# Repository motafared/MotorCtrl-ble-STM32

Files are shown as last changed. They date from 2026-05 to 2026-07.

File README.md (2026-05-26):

# MotorCtrl BLE — STM32WB55 Dual BLDC Motor Controller (Phase 2)

Wireless control and live telemetry for a **dual 12 V BLDC motor controller**, built on the
**WeAct STM32WB55** (Cortex-M4 + Bluetooth LE 5.0). Phase 2 adds BLE control plus a
**Web Bluetooth dashboard** — drive the motors and watch live data from a phone or laptop, with
no app install. The original push-button control still works in parallel.

> 🌐 **Live dashboard:** **https://motafared.github.io/MotorCtrl-ble-STM32/** — open in
> Chrome / Edge on desktop or Android (no install). Needs Bluetooth on; Android also needs
> Location enabled for BLE scanning.
>
> 📄 **Full delivery document:** [`docs/phase2_delivery.md`](docs/phase2_delivery.md)
> ([styled HTML](docs/phase2_delivery.html)) — scope, BOM, wiring, flashing, GATT reference,
> dashboard usage, troubleshooting.

## Repository layout (monorepo)

```
Phase2-Project/
├── firmware/   STM32WB55 application (STM32CubeIDE) + BLE GATT services
├── WebApp/     Web Bluetooth dashboard (single-page, no install)
├── kicad/      Hardware design (KiCad, generated from SKiDL)
└── docs/       Delivery doc + connection diagrams
```

## At a glance

- **Two BLDC motors**, closed-loop PID speed control (100 ms tick), tachometer feedback.
- **Three run modes:** Timed run (default 35 s) · Continuous (CONTINUE button: run while held; app command: latched until Stop) · Stopped.
- **Live telemetry:** actual speed, cumulative rotations, elapsed time, and run state.
- **Buttons + BLE in parallel** — the dashboard tracks physical button presses live.

## Hardware

| Item | Detail |
|---|---|
| MCU | WeAct STM32WB55 Core Board (STM32WB55CGU6, 64 MHz, BLE 5.0) |
| Motors | 2× BLDC 12 V 4-wire |
| PWM | PA0 (M1) / PA1 (M2) — TIM2, 20 kHz |
| Tachometer | PA8 (M1) / PA9 (M2) — TIM1 input capture |
| PID tick | TIM16 — 100 ms |
| Buttons | PA2 STOP, PA3 START, PA4 CONTINUE — EXTI, **active-HIGH, internal pull-down** |
| Status LED | PE4 (blue) — ON running, 5 Hz heartbeat |

## BLE GATT

Advertised name **`MotorCtrl`**. All multi-byte values little-endian.

**Control service `0x0001`**

| Char | UUID | Type | Access | Meaning |
|---|---|---|---|---|
| TSM1 | 0x0002 | u16 | R/W | Target speed M1 (RPM) |
| TSM2 | 0x0003 | u16 | R/W | Target speed M2 (RPM) |
| CT | 0x0004 | u16 | R/W | Cycle time (s) |
| CMD | 0x0005 | u8 | W | `0x01` start timed · `0x02` stop · `0x03` start continuous |

**Telemetry service `0x0010`** (Read / Notify)

| Char | UUID | Type | Meaning |
|---|---|---|---|
| ASM1 / ASM2 | 0x0011 / 0x0012 | u16 | Actual speed M1 / M2 (RPM) |
| RM1 / RM2 | 0x0013 / 0x0014 | u32 | Cumulative rotations M1 / M2 |
| ET | 0x0015 | u16 | Elapsed time (s) |
| STATUS | 0x0016 | u8 | Run state: `0` idle · `1` timed · `2` continuous |

Reads return live values (refreshed from firmware state on each read). STATUS is notified on
every transition — BLE command, timed auto-stop, **and** physical button presses.

## Build & flash (firmware)

This project is **STM32CubeIDE only**.

1. **One-time:** flash the CPU2 BLE stack with STM32CubeProgrammer — `stm32wb5x_FUS_fw.bin` at
   `0x080EC000` (skip if FUS ≥ 1.2.0), then `stm32wb5x_BLE_Stack_full_fw.bin` at `0x080C0000`.
2. Open `firmware/` in STM32CubeIDE → **Build All** → **Run** to flash the application.

**Build modes** — one switch in `firmware/Core/Inc/main.h`:

| `MOTOR_MODE` | Tacho PPR | PWM polarity | Use |
|---|---|---|---|
| `MODE_KHALED` | 2 | non-inverted | bench testing |
| `MODE_TOON` | 6 | inverted | client hardware |

Defaults: target 1200 RPM/motor, 35 s cycle, PID `Kp = 0.012`.

## Run the dashboard

**Hosted (no install):** open **https://motafared.github.io/MotorCtrl-ble-STM32/** in Chrome / Edge.

Or serve it locally:

```bash
cd WebApp
python -m http.server 8000      # then open http://localhost:8000 in Chrome
```

- **Browsers:** Chrome / Edge / Brave (desktop, Android); **Bluefy** on iOS.
- Web Bluetooth needs a secure context (`https://` or `http://localhost`); `file://` won't work.
- After flashing new firmware, **hard-reload** the page (Ctrl+Shift+R) to avoid a cached script.

## License

Proprietary — all rights reserved. Client project for Toon.

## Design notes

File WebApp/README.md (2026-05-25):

# MotorCtrl WebApp

Web Bluetooth dashboard for the **MotorCtrl** STM32WB55 BLDC controller (Phase 2 firmware).

- Connect to the board over BLE 5 directly from the browser — no install.
- Live actual / target RPM for both motors, rotation counts, elapsed time.
- Start (timed), Stop, Start (continuous) commands.
- Live speed chart (60-second rolling window).
- Settings are locked while the motors are running (stop first to change).

## Browser support

- **Desktop / Android:** Google Chrome, Edge, Brave (any Chromium with Web Bluetooth).
- **iOS / iPadOS:** [Bluefy](https://apps.apple.com/app/bluefy-web-ble-browser/id1492822055) (free, App Store).

Web Bluetooth requires a secure context. Use `https://` (e.g. GitHub Pages) or `http://localhost` for development. `file://` is **not** supported.

## Run locally

```bash
python -m http.server 8000
# then open http://localhost:8000
```

## Firmware

See the firmware repo: [MotorCtrl-ble-STM32](https://github.com/motafared/MotorCtrl-ble-STM32).

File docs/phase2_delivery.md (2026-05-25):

# MotorCtrl — Phase 2 Delivery (BLE Wireless Control)

**Client:** Toon
**Scope:** STM32 firmware + Web Bluetooth dashboard that add wireless control and
live telemetry to the Phase 1 dual-BLDC motor controller.
**Hardware:** WeAct STM32WB55 Core Board (STM32WB55CGU6), two 12 V 4-wire BLDC
motors with 1-pulse-per-revolution tachometers, three push-buttons, status LED.

---

## 1. What this is

Phase 1 was a dual-BLDC speed controller on an STM32F103: two motors, PID speed
control, three run modes (timed / continuous / stopped), driven by on-board
buttons. **Phase 2 moves it to the STM32WB55** (same STM32 ecosystem, plus
built-in Bluetooth LE 5.0) and adds:

- **BLE control** — set target speeds and cycle time, and start/stop the motors,
  from a phone or laptop with no app install (a web page over Web Bluetooth).
- **BLE telemetry** — live actual speed, rotation counts, elapsed time, and run
  state pushed to the dashboard as they change.
- The original **push-button control still works** in parallel with BLE, and the
  dashboard tracks button presses live.

**In scope for Phase 2:**
- STM32WB55 firmware: motor PID port, BLE GATT services (control + telemetry),
  button + timed-cycle logic, status LED.
- Web Bluetooth dashboard (single-page, no install).
- This documentation.

**Out of scope / deferred (see §10):**
- Custom PCB build (a KiCad design exists under `kicad/`, not yet fabricated).
- Multi-board control (up to 4 boards in one browser tab) — architecture is
  ready, UI is single-board.
- Persisting settings across power cycles (flash storage).

---

## 2. Hardware bill of materials

| Item | Notes |
|---|---|
| WeAct STM32WB55 Core Board | STM32WB55CGU6, 64 MHz, BLE 5.0, supplied by client |
| 2× 12 V 4-wire BLDC motors | PWM + tachometer (1 pulse/rev sensed; see §4 for PPR) |
| 12 V DC supply | Motor rail; logic is 3.3 V from the board regulator |
| 3× momentary push-buttons | START / STOP / CONTINUE — see §3.2 wiring (active-HIGH) |
| 1× LED + ~1 kΩ resistor | Status indicator on PE4 |
| ST-LINK (or on-board) | Flashing / debug over SWD |
| Phone or PC with Chrome/Edge | To run the Web Bluetooth dashboard (§7) |

A detailed pin-by-pin wiring sheet and a styled connection diagram live in
`kicad/MotorCtrl/WIRING.md` and `kicad/MotorCtrl/connections.html`.

---

## 3. Hardware connections

All control logic is 3.3 V. The motors run on +12 V; share a common ground
between the 12 V supply and the board.

### 3.1 Pin map (STM32WB55, 64 MHz)

| Signal | STM32 Pin | Peripheral | Notes |
|---|---|---|---|
| Motor 1 PWM | PA0 | TIM2_CH1 | 20 kHz PWM |
| Motor 2 PWM | PA1 | TIM2_CH2 | 20 kHz PWM |
| Motor 1 tacho | PA8 | TIM1_CH1 | input capture |
| Motor 2 tacho | PA9 | TIM1_CH2 | input capture |
| Button STOP | PA2 | EXTI2 | active-HIGH, internal pull-down |
| Button START | PA3 | EXTI3 | active-HIGH, internal pull-down |
| Button CONTINUE | PA4 | EXTI4 | active-HIGH, internal pull-down |
| Status LED (blue) | PE4 | GPIO out | ON running, 5 Hz heartbeat |
| SWD debug | PA13 / PA14 | SWDIO / SWCLK | flashing |

Timer setup: TIM2 prescaler 0 / period 3199 → 20 kHz PWM at 64 MHz · TIM1
prescaler 999 → tacho input capture · TIM16 prescaler 6399 / period 999 →
100 ms PID + telemetry tick.

### 3.2 Push-buttons (active-HIGH, internal pull-down)

The buttons are wired **active-HIGH**: pressing a button connects the MCU pin to
**+3V3**. The MCU's **internal pull-down** holds the pin LOW when released, so
**no external pull resistor is required**.

```
   Push-buttons                      STM32WB55 board
   ┌─────────────────────┐          ┌──────────────────────────┐
   │ START   SW1 ────────├─────────►┤ PA3   BTN_START          │ EXTI3  rising (press)
   │ STOP    SW2 ────────├─────────►┤ PA2   BTN_STOP           │ EXTI2  rising (press)
   │ CONT    SW3 ────────├─────────►┤ PA4   BTN_CONTINUE       │ EXTI4  both edges
   │ (common → +3V3)     │          │   (internal pull-down ON) │
   └─────────────────────┘          └──────────────────────────┘
```

- **Idle = LOW**, **pressed = HIGH**.
- START / STOP act on the **rising edge** (the press).
- CONTINUE uses **both edges**: rising = start (runs while held), falling =
  release = stop.
- Firmware debounces 50 ms in software; an optional series resistor + small cap
  to GND is fine for ESD but not electrically required.

> ⚠ This differs from the older active-low note in some early hardware drafts.
> The firmware is the source of truth (`Core/Src/main.c` → `MX_GPIO_Init`,
> `GPIO_PULLDOWN`). The KiCad/SKiDL source (`kicad/MotorCtrl/motorctrl.py`) must
> match: button common to **+3V3**, external pull-ups removed.

### 3.3 Motors

```
   Motor M1 (4-wire)                 STM32WB55 board
   +12V ───────────── +12 V rail
   GND  ───────────── GND (common with board GND)
   PWM  ◄──────────── PA0  (TIM2_CH1)
   Tacho ──────────►  PA8  (TIM1_CH1)

   Motor M2 (4-wire)
   PWM  ◄──────────── PA1  (TIM2_CH2)
   Tacho ──────────►  PA9  (TIM1_CH2)
```

Each tacho line typically needs a pull-up to +3V3. The PWM output idles at the
inactive level until a motor is started (see §9 troubleshooting on bench
behaviour with no motor connected).

---

## 4. Build modes (Khaled vs Toon)

A single switch in `Core/Inc/main.h` selects between the bench-test setup and the
client hardware, because they differ in tachometer pulses-per-revolution and PWM
polarity:

```c
#define MOTOR_MODE   MODE_KHALED   /* <<< switch here: MODE_KHALED or MODE_TOON */
```

| Mode | `MOTOR_PPR` | PWM polarity | Use |
|---|---|---|---|
| `MODE_KHALED` | 2 | `TIM_OCPOLARITY_HIGH` (not inverted) | bench testing |
| `MODE_TOON` | 6 | `TIM_OCPOLARITY_LOW` (inverted) | client hardware |

`M1_PPR` / `M2_PPR` follow `MOTOR_PPR`. PWM polarity is re-applied in the
`USER CODE BEGIN TIM2_Init 2` block of `Core/Src/main.c` so it survives CubeMX
regeneration. **Flip the one `MOTOR_MODE` line and rebuild** to switch targets —
nothing else changes. Default ships as `MODE_KHALED`.

Other defaults (`main.h`): target speed 1200 RPM per motor, cycle time 35 s
(timed mode), PID `Kp = 0.012`, `Ki = 0`, `Kd = 0`, 100 ms control tick.

---

## 5. Firmware install

The STM32WB55 has **two cores**: the application runs on the CM4; the BLE stack
runs on a CM0+ co-processor and is flashed **separately**. You must have the BLE
stack in place once before the application's Bluetooth will work.

### 5.1 Flash the BLE co-processor stack (one-time, STM32CubeProgrammer)

Binaries come from the **STM32CubeWB** package:
`STM32Cube_FW_WB_Vx.x.x\Projects\STM32WB_Copro_Wireless_Binaries\STM32WB5x\`.

1. Connect via ST-LINK; open **STM32CubeProgrammer**.
2. Flash **FUS** `stm32wb5x_FUS_fw.bin` at **`0x080EC000`** — skip if a recent
   FUS (≥ 1.2.0) is already present.
3. Flash the **BLE Full stack** `stm32wb5x_BLE_Stack_full_fw.bin` at
   **`0x080C0000`** (this project uses `BLE_STACK=FULL`).
4. Verify in the **Wireless** tab — it shows the installed FUS and BLE versions.

(If the stack is already installed and verified, skip to 5.2.)

### 5.2 Build and flash the application (STM32CubeIDE)

This project is **STM32CubeIDE only** (ignore the `EWARM/` folder).

1. Open **STM32CubeIDE** → **File → Open Projects from File System** → select the
   `Phase2/` project folder.
2. Confirm `MOTOR_MODE` in `main.h` (§4) is set for the board you're flashing.
3. **Project → Build All** — should complete with **0 errors**.
4. **Run → Run As → STM32 C/C++ Application** to flash the CM4 application at
   `0x08000000` and start it.

### 5.3 Verify it's alive

- The **blue LED (PE4)** is OFF when stopped. Press **START** → motors run and the
  LED blinks ~5 Hz (the PID-tick heartbeat). Press **STOP** → LED off.
- From a phone/PC, the board advertises as **`MotorCtrl`** and is visible to a BLE
  scanner (nRF Connect) or the dashboard (§7).

---

## 6. BLE GATT reference

- **Advertised name:** `MotorCtrl`
- **All multi-byte values are little-endian.**
- Two services: **Control** (write settings + commands) and **Telemetry**
  (read + notify live values).

### 6.1 Control service — UUID `0x0001`

| Characteristic | UUID | Type | Properties | Meaning |
|---|---|---|---|---|
| TSM1 | `0x0002` | uint16 | Read / Write | Target speed motor 1 (RPM) |
| TSM2 | `0x0003` | uint16 | Read / Write | Target speed motor 2 (RPM) |
| CT | `0x0004` | uint16 | Read / Write | Cycle time (seconds, timed mode) |
| CMD  | `0x0005` | uint8  | Write | Command: `0x01` start timed · `0x02` stop · `0x03` start continuous |

### 6.2 Telemetry service — UUID `0x0010`

| Characteristic | UUID | Type | Properties | Meaning |
|---|---|---|---|---|
| ASM1 | `0x0011` | uint16 | Read / Notify | Actual speed motor 1 (RPM) |
| ASM2 | `0x0012` | uint16 | Read / Notify | Actual speed motor 2 (RPM) |
| RM1  | `0x0013` | uint32 | Read / Notify | Cumulative rotations motor 1 |
| RM2  | `0x0014` | uint32 | Read / Notify | Cumulative rotations motor 2 |
| ET | `0x0015` | uint16 | Read / Notify | Elapsed time (seconds) |
| STATUS | `0x0016` | uint8 | Read / Notify | Run state: `0` idle · `1` timed · `2` continuous |

### 6.3 Behaviour notes

- **Reads return live values.** A read of any characteristic refreshes it from the
  firmware's current state before answering (not a stale cache), so a client that
  connects mid-run sees the true values immediately.
- **STATUS is the source of truth for run state.** The firmware notifies STATUS on
  **every** transition — BLE command, timed auto-stop, *and* physical button
  presses — so a dashboard always reflects what the board is actually doing.
- Telemetry notifications are emitted every 100 ms while running, from a safe BLE
  task context (not from an interrupt).

---

## 7. Web Bluetooth dashboard

A single-page dashboard (in the `WebApp/` folder) that connects to the board over
BLE — **no install**.

### 7.1 Browser support

- **Desktop / Android:** Google Chrome, Edge, or Brave (any Chromium with Web
  Bluetooth).
- **iPhone / iPad:** the **Bluefy** browser (free, App Store) — Safari does not
  support Web Bluetooth.
- Web Bluetooth requires a **secure context**: serve over `https://` (e.g. GitHub
  Pages) or `http://localhost`. Opening the file directly (`file://`) will not
  work.

### 7.2 Run it locally

```bash
cd WebApp
python -m http.server 8000
# open http://localhost:8000 in Chrome
```

### 7.3 Using it

1. Click **Connect** and pick **MotorCtrl** from the chooser.
2. The dashboard hydrates from the board: target speeds, cycle time, live RPM,
   rotation counts, elapsed time, and run state.
3. Set **Target** speed per motor and the **Cycle** time, then **Start Timed**,
   **Start Continuous**, or **Stop**.
4. The **Live Speed** chart shows actual vs target RPM over a 60 s rolling window.
5. Settings are **locked while running** — stop first to change them.
6. The state chip and lock track the board live, including physical-button
   presses and the automatic stop at the end of a timed run.

> **After flashing new firmware, hard-reload the page** (Ctrl+Shift+R). Browsers
> cache the dashboard's scripts; a stale cache can keep telemetry working while
> new features silently don't.

---

## 8. Operation summary

| Action | Button | BLE command | Result |
|---|---|---|---|
| Start timed run | START (PA3) | CMD `0x01` | Both motors run to target speed; auto-stop after the cycle time (default 35 s). |
| Stop | STOP (PA2) | CMD `0x02` | Motors stop immediately, any mode. |
| Start continuous | CONTINUE (PA4), held | CMD `0x03` | Motors run; **button mode stops on release**. |

- **Speed control** is closed-loop PID using the tachometer; target defaults to
  1200 RPM and is adjustable live over BLE.
- **Rotations** accumulate while running and are reported live and at cycle end.
- The **blue LED** is ON (blinking 5 Hz) while running, OFF when stopped.

---

## 9. Troubleshooting

| Symptom | Likely cause | Fix |
|---|---|---|
| Dashboard can't find the board | BLE stack not flashed, or board not advertising | Verify CPU2 stack in CubeProgrammer **Wireless** tab (§5.1); confirm `MotorCtrl` shows in a BLE scanner |
| "GATT Server is disconnected. Cannot retrieve services" (intermittent) | Web Bluetooth + WB connection race | The dashboard retries automatically; if persistent, forget the device in OS Bluetooth and reconnect |
| Connected, telemetry works, but run-state/buttons don't update the UI | Browser serving a cached old dashboard | **Hard-reload** the page (Ctrl+Shift+R), or DevTools → Network → "Disable cache" |
| No PWM on the analyser with no motor connected | Open-loop PID winds duty to 100% (no feedback) → pin sits constant HIGH | Expected on the bench; connect a motor for closed-loop, or temporarily zero the PID gains / force a fixed duty |
| Motor doesn't reach/track speed | Wrong `MOTOR_MODE` PPR, or tacho not wired | Confirm `MODE_KHALED` (PPR 2) vs `MODE_TOON` (PPR 6) matches the motor; check tacho pull-up and wiring |
| Button does nothing / triggers inverted | Button wired active-low instead of active-HIGH | Wire button common to **+3V3** (§3.2); firmware uses internal pull-down |
| Settings won't change in the dashboard | Motors are running (settings locked) | Press **Stop** first, then edit |
| Build fails after editing BLE chars in CubeMX | CubeMX caps STM32WB services at 5 characteristics | The 6th char (STATUS) is added in code, not the `.ioc`; see §10 |

---

## 10. Production notes & deferred items

- **STM32WB CubeMX 5-characteristic limit.** The CubeMX GATT designer caps each
  STM32WB service at 5 characteristics. The 6th telemetry characteristic
  (**STATUS**) is therefore added **manually in code** (ST's recommended
  workaround: `aci_gatt_add_char()` + increased `max_attr_record`). Because it
  lives partly outside CubeMX user-code regions, **re-running CubeMX "Generate
  Code" will wipe parts of it** — re-apply from the firmware history if you
  regenerate, or freeze the `.ioc`.
- **Multi-board dashboard.** The web app's BLE layer is one-instance-per-device
  and event-driven, ready for the "up to 4 boards in one tab" requirement; only
  the UI is currently single-board.
- **Persistent settings.** Target speeds / cycle time reset to defaults on power
  cycle. A future revision could store them in flash.
- **Custom PCB.** A KiCad design exists under `kicad/MotorCtrl/` (SKiDL source
  `motorctrl.py`). It must be brought in line with the firmware before
  fabrication — notably the **active-HIGH button wiring** (§3.2).
- **Watchdog / fault handling.** No IWDG is enabled; consider one for unattended
  operation.

---

*Document version: Phase 2 — 2026-05-25*

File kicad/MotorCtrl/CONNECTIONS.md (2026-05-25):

# MotorCtrl — Connections to the STM32 Board

Wiring of the **STM32WB55** carrier board (Phase 2), one connection group per
diagram. Pins mirror the firmware map in `Core/Inc/main.h`; source of truth is
the SKiDL design [motorctrl.py](motorctrl.py).

Board MCU module: **WeAct STM32WB55CGU6** (`U2`). All `3V3` logic; motors run on
the `+12V` rail.

---

## 1. STM32 ↔ Motors

Two 4-wire BLDC motors on connectors `J3` (M1) and `J4` (M2). PWM drives the
motor; the tacho returns one pulse train per revolution.

```
   Motor M1  (J3, 4-wire)            STM32WB55 board (U2)
   ┌─────────────────────┐          ┌──────────────────────────┐
   │ +12V   (J3.2)       ├── +12V ───┤ +12V rail                │
   │ GND    (J3.1)       ├── GND  ───┤ GND                      │
   │ PWM    (J3.3)       ├◄──────────┤ PA0   M1_PWM             │ TIM2_CH1
   │ Tacho  (J3.4)       ├──────────►┤ PA8   M1_TACH            │ TIM1_CH1
   └─────────────────────┘          └──────────────────────────┘

   Motor M2  (J4, 4-wire)            STM32WB55 board (U2)
   ┌─────────────────────┐          ┌──────────────────────────┐
   │ +12V   (J4.2)       ├── +12V ───┤ +12V rail                │
   │ GND    (J4.1)       ├── GND  ───┤ GND                      │
   │ PWM    (J4.3)       ├◄──────────┤ PA1   M2_PWM             │ TIM2_CH2
   │ Tacho  (J4.4)       ├──────────►┤ PA9   M2_TACH            │ TIM1_CH2
   └─────────────────────┘          └──────────────────────────┘
```

- Each tacho line has a pull-up to `+3V3` on the board: `R1` (M1), `R2` (M2).
- PWM is 20 kHz (TIM2); tacho is timer input-capture (TIM1).

---

## 2. STM32 ↔ Buttons

Three momentary push-buttons. Each is debounced on the board: pull-up to `+3V3`,
series resistor to the switch, and a cap to `GND`. The switch pulls the MCU pin
low when pressed.

```
   Push-buttons                      STM32WB55 board (U2)
   ┌─────────────────────┐          ┌──────────────────────────┐
   │ START   SW1 ─[R6]───├──────────►┤ PA3   BTN_START          │ EXTI3
   │ STOP    SW2 ─[R7]───├──────────►┤ PA2   BTN_STOP           │ EXTI2
   │ CONT    SW3 ─[R8]───├──────────►┤ PA4   BTN_CONTINUE       │ EXTI4
   │ (cold side → GND)   │          │                          │
   └─────────────────────┘          └──────────────────────────┘
```

- Per pin on the board: pull-up `R3/R4/R5` → `+3V3`, debounce cap `C7/C8/C9` → `GND`.
- Idle = high (3V3); pressed = low. All three fire EXTI interrupts.

---

## 3. STM32 ↔ Status LED

```
   STM32WB55 board (U2)              Status LED
   ┌──────────────────────────┐     ┌──────────────┐
   │ PE4   LED_DRIVE ─[R9 1k]──├────►┤ D2 anode     │
   │ GND ──────────────────────├─────┤ D2 cathode   │
   └──────────────────────────┘     └──────────────┘
```

- `PE4` high → LED on (motors running / heartbeat). `R9` = 1 kΩ series.

---

## 4. STM32 ↔ SWD programmer

5-pin header `J5` for flashing/debug (ST-LINK).

```
   SWD header (J5, 1×5)              STM32WB55 board (U2)
   ┌─────────────────────┐          ┌──────────────────────────┐
   │ +3V3   (J5.1)       ├── 3V3 ────┤ +3V3                     │
   │ SWDIO  (J5.2)       ├──────────►┤ PA13  SWDIO              │
   │ SWCLK  (J5.3)       ├──────────►┤ PA14  SWCLK              │
   │ NRST   (J5.4)       ├──────────►┤ NRST                     │
   │ GND    (J5.5)       ├── GND ────┤ GND                      │
   └─────────────────────┘          └──────────────────────────┘
```

---

## 5. Power input

12 V DC barrel jack → reverse-polarity Schottky → on-board regulator.

```
   12 V DC jack (J1)        Board power stage                  Rails
   ┌─────────────────┐      ┌──────────────────────────┐      ┌──────────┐
   │ +12V   (J1.1)   ├─ D1 ─┤ Schottky → +12V rail       ├────►│ +12V     │
   │                 │      │ AMS1117 (U1): 12V → 3.3V   ├────►│ +3V3     │
   │ GND    (J1.2)   ├──────┤ common ground              ├────►│ GND      │
   └─────────────────┘      └──────────────────────────┘      └──────────┘
```

- `+12V` rail → motors (`J3.2`/`J4.2`) + decoupling. `+3V3` → `U2`, pull-ups, SWD.

---

For the pin-by-pin schematic-drawing checklist see [WIRING.md](WIRING.md);
for the rendered version open [connections.html](connections.html).

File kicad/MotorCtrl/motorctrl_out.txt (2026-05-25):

python : WARNING: KICAD6_SYMBOL_DIR environment variable is missing, so the default KiCad symbol libraries won't be 
searched. @ [E:\projects\STM32 bldc motor\Phase2\kicad\MotorCtrl\<frozen 
importlib._bootstrap_external>:728=>E:\projects\STM32 bldc motor\Phase2\kicad\MotorCtrl\<frozen 
importlib._bootstrap>:219]
At line:1 char:59
+ ... icad\MotorCtrl"; python motorctrl.py > motorctrl_out.txt 2>&1; Get-Co ...
+                      ~~~~~~~~~~~~~~~~~~~~~~~~~~~~~~~~~~~~~~~~~~~~
    + CategoryInfo          : NotSpecified: (WARNING: KICAD6...bootstrap>:219]:String) [], RemoteException
    + FullyQualifiedErrorId : NativeCommandError
 
WARNING: fp-lib-table file was not found. Component footprints are not available.
WARNING: fp-lib-table file was not found. Component footprints are not available.
WARNING: fp-lib-table file was not found. Component footprints are not available.
WARNING: fp-lib-table file was not found. Component footprints are not available.
ERC WARNING: Insufficient drive current on net +12V for pin POWER-IN pin 3/VI of AMS1117-3.3/U1.
ERC WARNING: Insufficient drive current on net GND for pin POWER-IN pin 1/GND of AMS1117-3.3/U1.
ERC WARNING: Insufficient drive current on net GND for pin POWER-IN pin 2/GND of WeAct_STM32WB55/U2.
ERC INFO: 3 warnings found while running ERC.
ERC INFO: 0 errors found while running ERC.

WARNING: Missing tag on Barrel_Jack instantiated at E:\projects\STM32 bldc 
motor\Phase2\kicad\MotorCtrl\motorctrl.py:74.
WARNING: Random tag 0QUBoadOpr generated for Barrel_Jack.
WARNING: Missing tag on C_Polarized instantiated at E:\projects\STM32 bldc 
motor\Phase2\kicad\MotorCtrl\motorctrl.py:79.
WARNING: Random tag zwmTBQ1yaq generated for C_Polarized.
WARNING: Missing tag on D_Schottky instantiated at E:\projects\claude-hw-lib\blocks\reverse_polarity_schottky.py:31.
WARNING: Random tag DAgKvcCYVF generated for D_Schottky.
WARNING: Missing tag on AMS1117-3.3 instantiated at E:\projects\claude-hw-lib\blocks\linear_3v3_supply.py:25.
WARNING: Random tag HcZivgtToc generated for AMS1117-3.3.
WARNING: Missing tag on C_Polarized instantiated at E:\projects\claude-hw-lib\blocks\linear_3v3_supply.py:26.
WARNING: Random tag gbFF1NG8wd generated for C_Polarized.
WARNING: Missing tag on C_Polarized instantiated at E:\projects\claude-hw-lib\blocks\linear_3v3_supply.py:27.
WARNING: Random tag fZl4WO7TRF generated for C_Polarized.
WARNING: Missing tag on C instantiated at E:\projects\claude-hw-lib\blocks\linear_3v3_supply.py:28.
WARNING: Random tag YcGgOmDWNa generated for C.
WARNING: Missing tag on WeAct_STM32WB55 instantiated at E:\projects\claude-hw-lib\parts\weact_stm32wb55.py:29.
WARNING: Random tag Hki1z7Uy_3 generated for WeAct_STM32WB55.
WARNING: Missing tag on Conn_01x04 instantiated at E:\projects\claude-hw-lib\blocks\motor_connector_4wire.py:46.
WARNING: Random tag hVulPy8_Qr generated for Conn_01x04.
WARNING: Missing tag on C instantiated at E:\projects\claude-hw-lib\blocks\motor_connector_4wire.py:53.
WARNING: Random tag ncZF6A22QD generated for C.
WARNING: Missing tag on R instantiated at E:\projects\claude-hw-lib\blocks\motor_connector_4wire.py:58.
WARNING: Random tag 3osAKWxwVv generated for R.
WARNING: Missing tag on Conn_01x04 instantiated at E:\projects\claude-hw-lib\blocks\motor_connector_4wire.py:46.
WARNING: Random tag zRdiGx68uh generated for Conn_01x04.
WARNING: Missing tag on C instantiated at E:\projects\claude-hw-lib\blocks\motor_connector_4wire.py:53.
WARNING: Random tag msYDPhdTO4 generated for C.
WARNING: Missing tag on R instantiated at E:\projects\claude-hw-lib\blocks\motor_connector_4wire.py:58.
WARNING: Random tag 7dWIRTKEch generated for R.
WARNING: Missing tag on SW_Push instantiated at E:\projects\claude-hw-lib\blocks\debounced_button.py:45.
WARNING: Random tag nblaOJSxVP generated for SW_Push.
WARNING: Missing tag on R instantiated at E:\projects\claude-hw-lib\blocks\debounced_button.py:46.
WARNING: Random tag wJFpgtXLLx generated for R.
WARNING: Missing tag on R instantiated at E:\projects\claude-hw-lib\blocks\debounced_button.py:47.
WARNING: Random tag E1nIbZEAbD generated for R.
WARNING: Missing tag on C instantiated at E:\projects\claude-hw-lib\blocks\debounced_button.py:48.
WARNING: Random tag AZF5RzJDIB generated for C.
WARNING: Missing tag on SW_Push instantiated at E:\projects\claude-hw-lib\blocks\debounced_button.py:45.
WARNING: Random tag BiCmzE_H9X generated for SW_Push.
WARNING: Missing tag on R instantiated at E:\projects\claude-hw-lib\blocks\debounced_button.py:46.
WARNING: Random tag MuFWJADk57 generated for R.
WARNING: Missing tag on R instantiated at E:\projects\claude-hw-lib\blocks\debounced_button.py:47.
WARNING: Random tag TCyMH7gSec generated for R.
WARNING: Missing tag on C instantiated at E:\projects\claude-hw-lib\blocks\debounced_button.py:48.
WARNING: Random tag PJt5gabX8I generated for C.
WARNING: Missing tag on SW_Push instantiated at E:\projects\claude-hw-lib\blocks\debounced_button.py:45.
WARNING: Random tag hWi0q2FDUj generated for SW_Push.
WARNING: Missing tag on R instantiated at E:\projects\claude-hw-lib\blocks\debounced_button.py:46.
WARNING: Random tag ry7J1vvkPQ generated for R.
WARNING: Missing tag on R instantiated at E:\projects\claude-hw-lib\blocks\debounced_button.py:47.
WARNING: Random tag CjMFyhNSTM generated for R.
WARNING: Missing tag on C instantiated at E:\projects\claude-hw-lib\blocks\debounced_button.py:48.
WARNING: Random tag rHuJxHpv0i generated for C.
WARNING: Missing tag on R instantiated at E:\projects\STM32 bldc motor\Phase2\kicad\MotorCtrl\motorctrl.py:133.
WARNING: Random tag L0kqfDBlKn generated for R.
WARNING: Missing tag on LED instantiated at E:\projects\STM32 bldc motor\Phase2\kicad\MotorCtrl\motorctrl.py:135.
WARNING: Random tag oq0q9vU3ZJ generated for LED.
WARNING: Missing tag on Conn_01x05 instantiated at E:\projects\STM32 bldc 
motor\Phase2\kicad\MotorCtrl\motorctrl.py:146.
WARNING: Random tag lNulxKPzLR generated for Conn_01x05.
WARNING: Missing tag on  instantiated at E:\projects\STM32 bldc motor\Phase2\kicad\MotorCtrl\<frozen 
importlib._bootstrap>:219.
INFO: 63 warnings found while generating netlist.
INFO: 0 errors found while generating netlist.

WARNING: Routing failed on attempt 1/2, expanding area by 1.5x:  @ [E:\projects\STM32 bldc 
motor\Phase2\kicad\MotorCtrl\motorctrl.py:175]
WARNING: Routing failed on attempt 2/2, expanding area by 1.5x:  @ [E:\projects\STM32 bldc 
motor\Phase2\kicad\MotorCtrl\motorctrl.py:175]
Traceback (most recent call last):
  File "C:\Users\motaf\AppData\Local\Programs\Python\Python37\lib\site-packages\skidl\schematics\route.py", line 3177, 
in route
    global_routes = node.global_router(internal_nets)
  File "C:\Users\motaf\AppData\Local\Programs\Python\Python37\lib\site-packages\skidl\schematics\route.py", line 2351, 
in global_router
    next_route = rt_srch(start_face, stop_faces)
  File "C:\Users\motaf\AppData\Local\Programs\Python\Python37\lib\site-packages\skidl\schematics\route.py", line 2289, 
in rt_srch
    f"Global routing failure: {net.name} {net} {start_face.pins}"
skidl.schematics.route.GlobalRoutingFailure: Global routing failure: BTN_CONTINUE BTN_CONTINUE: Pin 
C7/1/,p1,p1862025783353331040/PASSIVE, Pin NT31/1/~,p1366970703523469591,p1,~/UNSPECIFIED, Pin 
R5/2/,p7724572544059326380,p2/PASSIVE, Pin R6/1/,p1,p2626926670313836656/PASSIVE, Pin 
U2/8/PA4_BTN_CONTINUE,p8,p3132780050032510598,PA4_BTN_CONTINUE/INPUT [Pin R5/2/,p7724572544059326380,p2/PASSIVE]

During handling of the above exception, another exception occurred:

Traceback (most recent call last):
  File "motorctrl.py", line 175, in <module>
    generate_schematic(
  File "C:\Users\motaf\AppData\Local\Programs\Python\Python37\lib\site-packages\skidl\circuit.py", line 1319, in 
generate_schematic
    tool_modules[tool].gen_schematic(self, **kwargs)
  File "C:\Users\motaf\AppData\Local\Programs\Python\Python37\lib\site-packages\skidl\tools\kicad9\gen_schematic.py", 
line 708, in gen_schematic
    raise failure_type
  File "C:\Users\motaf\AppData\Local\Programs\Python\Python37\lib\site-packages\skidl\tools\kicad9\gen_schematic.py", 
line 597, in gen_schematic
    node.route(**options)
  File "C:\Users\motaf\AppData\Local\Programs\Python\Python37\lib\site-packages\skidl\schematics\route.py", line 3236, 
in route
    raise RoutingFailure
skidl.schematics.route.RoutingFailure

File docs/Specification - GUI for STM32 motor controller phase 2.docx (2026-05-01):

Specification: Graphical User Interface (GUI) for STM32 motor controller

1. Introduction

A set of two BLDC motors is by controlled by a PID motor controller on a STM32 board for an application. Currently, the target speed of motor 1.1 and motor 1.2 and cycle time are programmed in the software code.

The settings for target speed and cycle time need to be changed within ca. 30 seconds for the application to find the correct settings for testing. Therefore, an HMI is required for fast changing of controller settings.

For flexibility, the GUI should be displayed on a PC based touch screen and have wireless Bluetooth connection with the motor controller.

2. Platform
  1. Controller board (STM32, for example NUCLEO-F746ZG (https://www.st.com/en/evaluation-tools/nucleo-f746zg.html) in combination with Bluetooth expansion board X-NUCLEO-67W61M1 (https://www.st.com/en/evaluation-tools/x-nucleo-67w61m1.html))
  2. PC based touch screen (Android, Linux and Windows)
  3. Web based Gui (Mongoose (https://mongoose.ws/) or similar)
3. Software requirements for the GUI and STM32 board
- Display on the GUI of
  - Actual target speed setting motor 1.1
  - Actual target speed setting motor 1.2
  - Actual cycle time setting
  - Cumulative rotations motor 1.1, overwrite at start of next cycle
  - Cumulative rotations motor 1.2, overwrite at start of next cycle
  - Elapsed cycle time of motor 1.1, overwrite at start of next cycle
  - Elapsed cycle time of motor 1.2, overwrite at start of next cycle
- Change setting via the GUI of
  - Target speed motor 1.1
  - Target speed motor 1.2
  - Cycle time
- Buttons
  - Momentary start button: cycle time = time set in code of STM32 board
  - Momentary stop button: cycle stop (manual, stops cycle time set in code of STM32 board)
  - Momentary start button: cycle time = time the button is pressed
- Modularity
  - In the future plug & play expandable to 4 sets of BLDC motors
  - Scenario 1: Each set of BLDC motors has its own PID motor controller board with its own Bluetooth communication to the central PC based touch screen with the web based GUI, see picture below
  - Scenario 2: All 4 sets of BLDC motors share one controller board with one Bluetooth communication to the central PC based touch screen with the web based GUI, see picture below
  - To be discussed: which scenario to choose based on e.g.
    - Flexibility
    - Modularity
    - Ease of use
    - Size
    - Cost

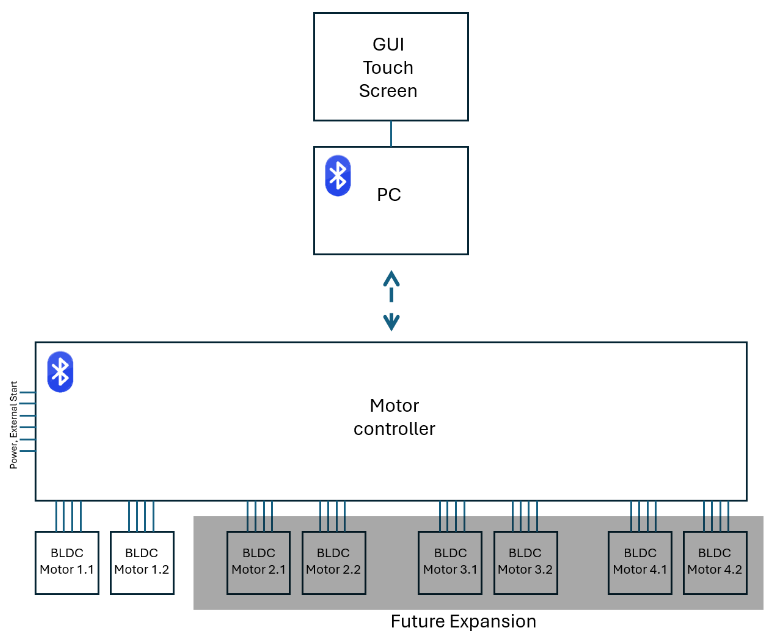
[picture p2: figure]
Afbeelding met tekst, schermopname, diagram, lijn Door AI gegenereerde inhoud is mogelijk onjuist.
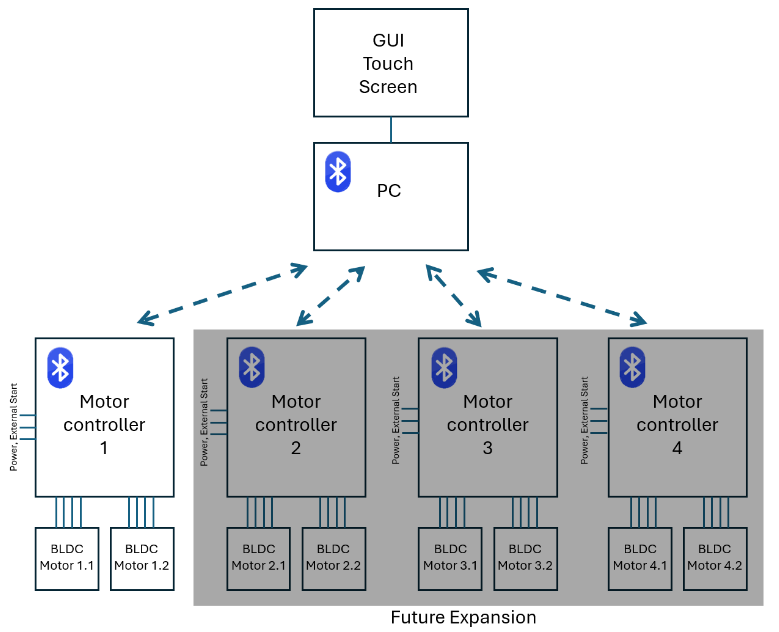
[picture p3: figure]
Afbeelding met tekst, diagram, schermopname, Plan Door AI gegenereerde inhoud is mogelijk onjuist.

Scenario 2

Scenario 1

4. Required scope of delivery
- Functional software for a PC based touch screen GUI and the STM32 boards as described above
- Software suitable for
  - uploading via STM32CubeIDE version 1.17.0 by us to our own STM32 board
  - installing on our own Windows PC

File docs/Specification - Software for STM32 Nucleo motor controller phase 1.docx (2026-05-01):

Specification: software for STM32 Nucleo motor controller

1. Introduction

A set of two BLDC motors must be controlled by a STM32 Nucleo-F103RB board. Required cycle see graph below:

- Both motor1 and motor 2 start at the same time and stop at the same time, both with the same given interval.
- Each motor must run at its own given constant speed
- A closed loop control (PID-control) is required to maintain the constant speed per motor at its target speed.

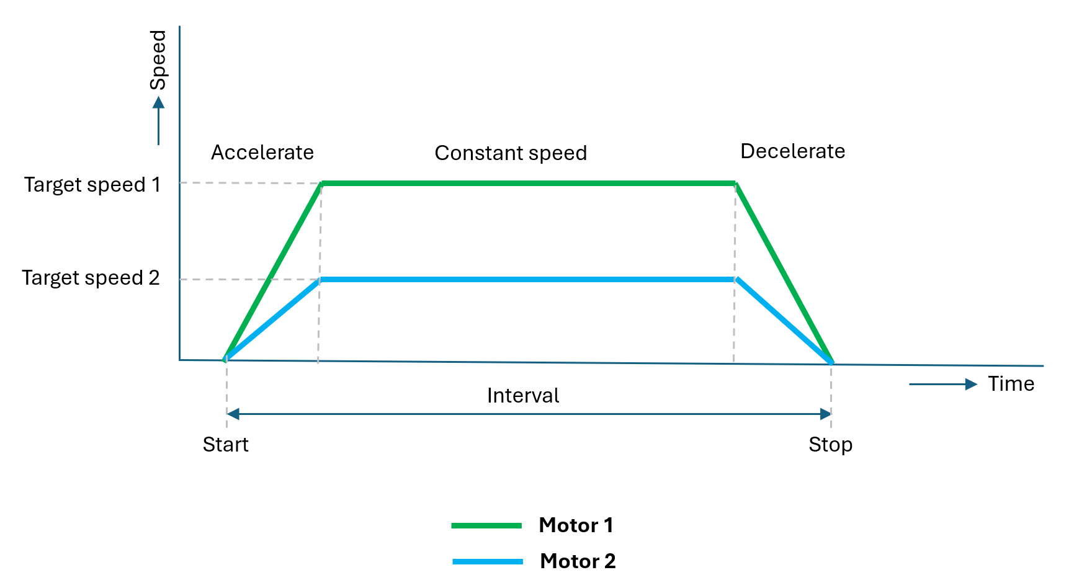
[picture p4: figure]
Afbeelding met diagram, lijn, tekst, schermopname Door AI gegenereerde inhoud is mogelijk onjuist.

2. BLDC motor specification
- Each BLCD motor has 4 wires
  1. PWM signal with a frequency of 20kHz as an input
    i. PWM control level “low”: ≤0.5V
    ii. PWM control level “high” 2.7 … 5.5V
  2. Tacho signal as an output
    i. FG-output pulses: 6 pulses / revolution
    ii. FG-output pulse time “low”: 50%
    iii. FG-output level “high” (no load): 5 … 6V
    iv. FG-output level “low” (no load): <0.5V
  3. + supply voltage (connected to external power supply)
  4. – supply voltage (connected to external power supply)
3. Software requirements for the STM32 Nucleo-F103RB board
- Programmed fixed in the C-program
  - One fixed PWM signal frequency setting of 20kHz for both motor 1 and motor 2
  - Target speed setting of 1900 rpm for motor 1
  - Target speed setting of 800 rpm for motor 2
  - PID parameter settings for motor 1
  - PID parameter settings for motor 2
  - One interval setting (time between start and stop) of 35 seconds for both motor 1 and motor 2
- Input 1: Start the interval with an input pulse HIGH (for a momentary push button)
- Input 2: Tacho signal from motor 1
- Input 3: Tacho signal from motor 2
- Output 1: PWM signal for motor 1
- Output 2: PWM signal for motor 2
- Plot speed of motor 1 and speed of motor 2 vs time elapsed using SWV data trace timeline graph in STM32CubeIDE
- Write cumulative rotations of motor 1 and motor 2 after completing a cycle in STM32CubeIDE
4. Required scope of delivery
- Functional software for the STM32 Nucleo-F103RB board as described above
- Software suitable for uploading via STM32CubeIDE version 1.17.0 by us to our own STM32 Nucleo-F103RB board for testing the complete system with the motors and power supply.

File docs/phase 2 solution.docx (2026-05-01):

Before I explain it, let me first close off the open points from our previous discussion.

STM32 and WiFi — No Single Chip Solution

As I mentioned earlier, STM32WB55 supports BLE only and aligns well with your BLE preference. After further research, I can confirm that the STM32 family does not offer a single chip solution combining motor control capabilities with integrated WiFi. Any WiFi-based approach would require an external module, adding hardware complexity and cost. Since your preference is BLE, this is not a concern — but it does rule out Mongoose in its standard form, as Mongoose requires a TCP/IP (WiFi) connection to serve its web interface.

Why Mongoose Does Not Work With BLE

Mongoose is a web server framework that operates over TCP/IP. The browser-based dashboard you saw in the Mongoose documentation is only possible when the device is connected via WiFi. There is no way to run Mongoose over a BLE connection regardless of the architecture.

The Architecture That Solves This — Web Bluetooth

You asked whether a different architecture could enable a browser-only, no-install solution over BLE. The answer is yes.

The approach is called Web Bluetooth. It is a modern browser capability that allows a web page running in Chrome to connect directly to a BLE device — with no backend service, no installed software, and no app store. This directly addresses the concern you raised about our Option 1 requiring a background service on the PC.

The solution works as follows. The dashboard is hosted online as a web page at a fixed URL — similar in concept to what you saw with Mongoose, but without requiring WiFi on the device. When a user wants to interact with the motor controllers, they simply open that URL in Chrome. The browser then connects directly to the STM32WB55 over Bluetooth. No installation of any kind is required on the user's device.

From the user's perspective:

- They open a link in Chrome, exactly like any website

- The browser asks permission to connect to the Bluetooth device

- The dashboard shows live speed curves, cumulative rotations, elapsed cycle time, and all settings

- Parameters can be changed and commands sent directly from the browser

- Nothing is installed on their machine

This also handles your modularity requirement cleanly. The browser can maintain simultaneous BLE connections to all four STM32WB55 controllers from a single tab, displaying each module in its own panel in one unified dashboard — matching your Scenario 1 from the specification.

Platform Compatibility

This solution works seamlessly on:

- ✅ Windows (Chrome or Edge)

- ✅ Linux (Chrome)

- ✅ Android phones and tablets (Chrome)

- ✅ macOS — Apple laptops and desktops (Chrome)

- ❌ iOS — iPhone and iPad

I want to be transparent about the iOS limitation. Apple currently does not allow browsers on iPhone and iPad to access Bluetooth. This is an Apple platform restriction and cannot be worked around without a dedicated iOS application. If iOS support is a firm requirement, we would need to discuss a separate native app for that platform, which would involve additional effort. If iOS is not critical for your users, all other platforms are fully covered with no installation needed.

Proposed Hardware

For the controller, we recommend the STM32WB55 — staying within the STM32 ecosystem as you prefer, with built-in BLE 5.0 and strong motor control peripherals, with no external wireless module required.

Please let us know whether iOS support is a requirement for your users, and we will finalize the architecture and move forward with the detailed proposal.

Best regards,

Khaled

Sunday, Mar 29

Khaled Hassanain

3:35 PM

Hi Toon,

One quick update on the iOS question — I found a clean solution.

On iOS, Web Bluetooth requires using a free browser called Bluefy (available on the App Store). It's a one-tap install, works exactly like installing Spotify. Once installed, the dashboard opens and works normally — no extra steps.

This means our Web Bluetooth dashboard works on:

- Android → Chrome (built-in)

- Desktop → Any browser

- iOS → Bluefy (free, one-tap)

No additional hardware or backend needed. I think this completes our solution.

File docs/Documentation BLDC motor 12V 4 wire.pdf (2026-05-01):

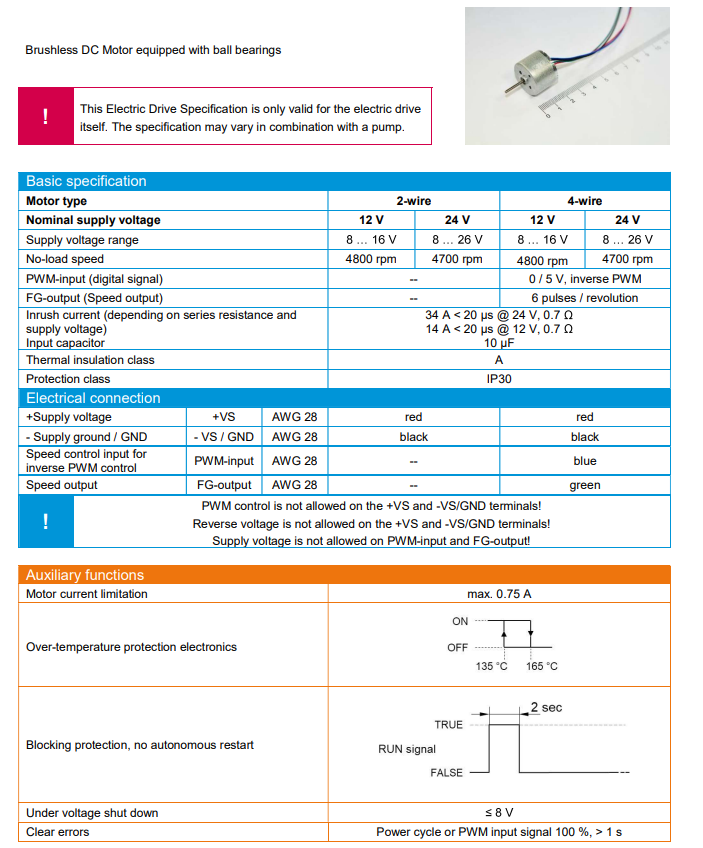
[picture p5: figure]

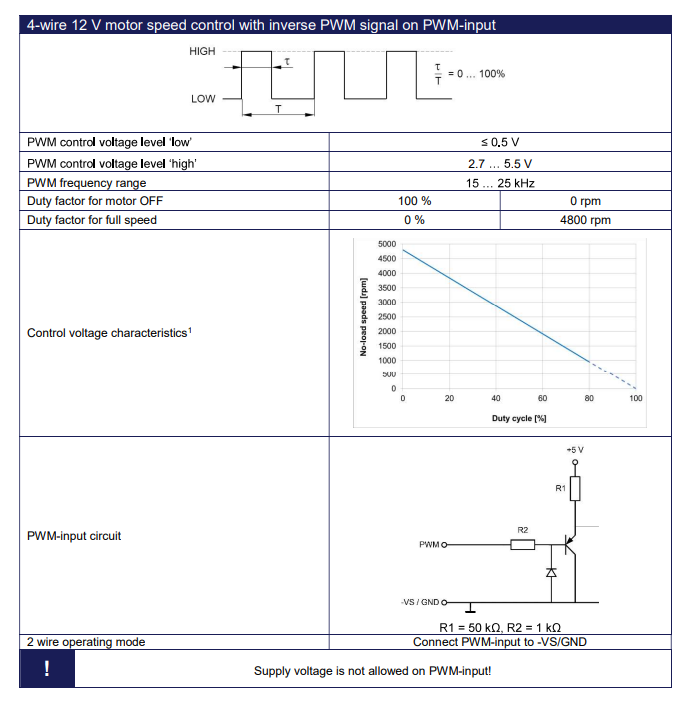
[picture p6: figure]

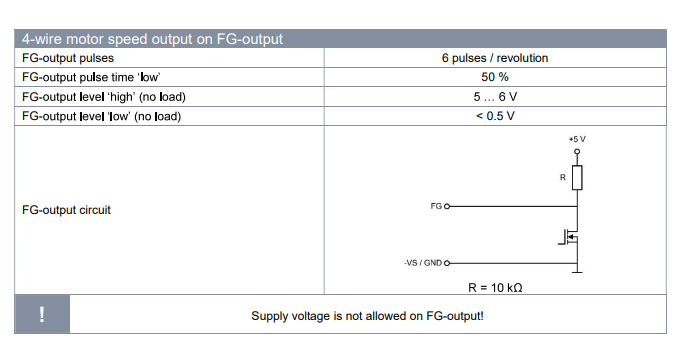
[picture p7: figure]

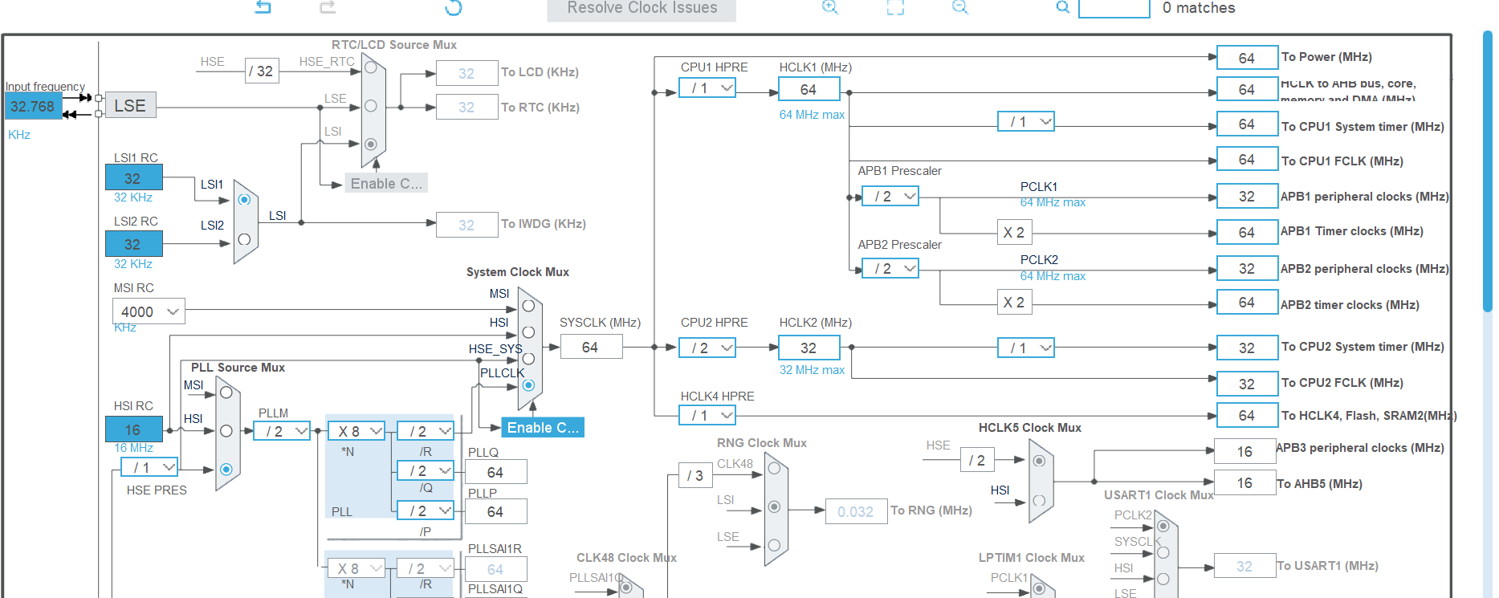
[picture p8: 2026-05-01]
docs/Screenshot 2026-04-30 080144.png

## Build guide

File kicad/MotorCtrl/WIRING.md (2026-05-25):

# MotorCtrl Schematic — Wiring Checklist

Work through each net below and draw wires (or place labels) in KiCad's schematic editor. Tick off each net as you complete it. ERC clean = done.

**Conventions:**
- Pin numbers come from the schematic symbol pin numbers (not MCU-package pins).
- For each net, the simplest approach in KiCad is to **place a global label** with the net name on each listed pin — KiCad connects them by name. No long wires needed.
- For power nets (`+12V`, `+3V3`, `GND`) use the matching **power symbol**, not a label.

---

## Power rails

### Net: `+12V`  *(use `+12V` power symbol on each pin)*
- [ ] **J1.1** — barrel jack (center +)  → goes to **D1.2 (A)** via short wire (this is the only wire-connection in the +12V chain — series reverse-polarity diode)
- [ ] **D1.1 (K)** — Schottky cathode = protected +12V (place +12V power symbol here)
- [ ] **C1.1** — 470 µF bulk cap, + side
- [ ] **C4.1** — 10 µF LDO input cap, + side
- [ ] **U1.3 (VI)** — AMS1117 input
- [ ] **C2.1** — 100 nF M1 decoupling
- [ ] **C3.1** — 100 nF M2 decoupling
- [ ] **J3.2** — motor M1 connector +12V pin
- [ ] **J4.2** — motor M2 connector +12V pin
- [ ] Place one **PWR_FLAG** symbol on this rail (so ERC sees it as driven)

### Net: `+3V3`  *(use `+3V3` power symbol on each pin)*
- [ ] **U1.2 (VO)** — AMS1117 output
- [ ] **C5.1** — 10 µF output cap, + side
- [ ] **C6.1** — 100 nF output decoupling
- [ ] **U2.1 (3V3)** — WB55 module 3V3
- [ ] **R1.1** — M1 tacho pull-up
- [ ] **R2.1** — M2 tacho pull-up
- [ ] **R3.1** — BTN_START pull-up
- [ ] **R4.1** — BTN_STOP pull-up
- [ ] **R5.1** — BTN_CONTINUE pull-up
- [ ] **J5.1** — SWD header 3V3
- [ ] Place one **PWR_FLAG** symbol on this rail

### Net: `GND`  *(use `GND` power symbol on each pin)*
- [ ] **J1.2** — barrel jack ring (−)
- [ ] **J1.3** — switch contact (tie to GND, or leave NC + add no-connect flag)
- [ ] **C1.2** — 470 µF, − side
- [ ] **U1.1 (GND)** — AMS1117 ground
- [ ] **C4.2** — 10 µF input cap, − side
- [ ] **C5.2** — 10 µF output cap, − side
- [ ] **C6.2** — 100 nF output decoupling
- [ ] **C2.2** — M1 decoupling
- [ ] **C3.2** — M2 decoupling
- [ ] **U2.2 (GND)** — WB55 module ground
- [ ] **J3.1** — motor M1 GND
- [ ] **J4.1** — motor M2 GND
- [ ] **SW1.1** — START button cold side
- [ ] **SW2.1** — STOP button cold side
- [ ] **SW3.1** — CONTINUE button cold side
- [ ] **C7.2** — START debounce cap
- [ ] **C8.2** — STOP debounce cap
- [ ] **C9.2** — CONTINUE debounce cap
- [ ] **D2.1 (K)** — LED cathode
- [ ] **J5.5** — SWD GND
- [ ] Place one **PWR_FLAG** symbol on this rail

---

## Motor signals

### Net: `M1_PWM`  *(label both pins `M1_PWM`)*
- [ ] **U2.4 (PA0/M1_PWM)**
- [ ] **J3.3** — motor M1 connector PWM pin

### Net: `M2_PWM`  *(label both pins `M2_PWM`)*
- [ ] **U2.5 (PA1/M2_PWM)**
- [ ] **J4.3** — motor M2 connector PWM pin

### Net: `M1_TACH`  *(label all three `M1_TACH`)*
- [ ] **U2.9 (PA8/M1_TACH)**
- [ ] **R1.2** — pull-up bottom side
- [ ] **J3.4** — motor M1 tacho pin

### Net: `M2_TACH`  *(label all three `M2_TACH`)*
- [ ] **U2.10 (PA9/M2_TACH)**
- [ ] **R2.2** — pull-up bottom side
- [ ] **J4.4** — motor M2 tacho pin

---

## Buttons (each has 2 nets)

Topology per button: pull-up R from MCU pin to +3V3, cap from MCU pin to GND, series R between switch and MCU pin, switch to GND.

### START button (PA3)
**Net: `BTN_START`** *(label these pins `BTN_START`)*
- [ ] **U2.7 (PA3/BTN_START)**
- [ ] **R3.2** — pull-up bottom
- [ ] **C7.1** — debounce cap top
- [ ] **R6.1** — series resistor, MCU side

**Net: `BTN_START_SW`** *(internal node between series R and switch)*
- [ ] **R6.2** — series resistor, switch side
- [ ] **SW1.2** — switch hot side

### STOP button (PA2)
**Net: `BTN_STOP`**
- [ ] **U2.6 (PA2/BTN_STOP)**
- [ ] **R4.2**
- [ ] **C8.1**
- [ ] **R7.1**

**Net: `BTN_STOP_SW`**
- [ ] **R7.2**
- [ ] **SW2.2**

### CONTINUE button (PA4)
**Net: `BTN_CONTINUE`**
- [ ] **U2.8 (PA4/BTN_CONTINUE)**
- [ ] **R5.2**
- [ ] **C9.1**
- [ ] **R8.1**

**Net: `BTN_CONTINUE_SW`**
- [ ] **R8.2**
- [ ] **SW3.2**

---

## LED (PE4)

### Net: `LED_DRIVE`  *(label both `LED_DRIVE`)*
- [ ] **U2.11 (PE4/LED)**
- [ ] **R9.1** — series resistor MCU side

### Net: `LED_A`  *(label both `LED_A`)*
- [ ] **R9.2** — series resistor LED side
- [ ] **D2.2 (A)** — LED anode

(D2.1 cathode → GND, already in GND list above.)

---

## SWD programming/debug

### Net: `SWDIO`
- [ ] **U2.12 (PA13/SWDIO)**
- [ ] **J5.2**

### Net: `SWCLK`
- [ ] **U2.13 (PA14/SWCLK)**
- [ ] **J5.3**

### Net: `NRST`
- [ ] **U2.3 (NRST)**
- [ ] **J5.4**

(J5.1 = +3V3, J5.5 = GND — already covered.)

---

## After wiring — ERC checklist

1. **Inspect → Electrical Rules Checker → Run ERC**.
2. Expected to pass clean. If not, common causes:
   - **"Pin not connected"** → missed a pin in the lists above.
   - **"Power pin not driven"** → a `+12V` / `+3V3` / `GND` rail is missing its `PWR_FLAG`.
   - **"Label dangling"** → a label was placed near but not on a pin endpoint. Drag it onto the pin tip.
   - **"Lib symbol mismatch"** → can be ignored (KiCad noticed our embedded symbols differ slightly from its installed library copies).
3. Cross-check pin assignments visually against `Core/Inc/main.h:65-83`.

## Net summary count

13 nets total: `+12V`, `+3V3`, `GND`, `M1_PWM`, `M2_PWM`, `M1_TACH`, `M2_TACH`, `BTN_START`, `BTN_START_SW`, `BTN_STOP`, `BTN_STOP_SW`, `BTN_CONTINUE`, `BTN_CONTINUE_SW`, `LED_DRIVE`, `LED_A`, `SWDIO`, `SWCLK`, `NRST` → **18 nets** (3 power + 15 signal).

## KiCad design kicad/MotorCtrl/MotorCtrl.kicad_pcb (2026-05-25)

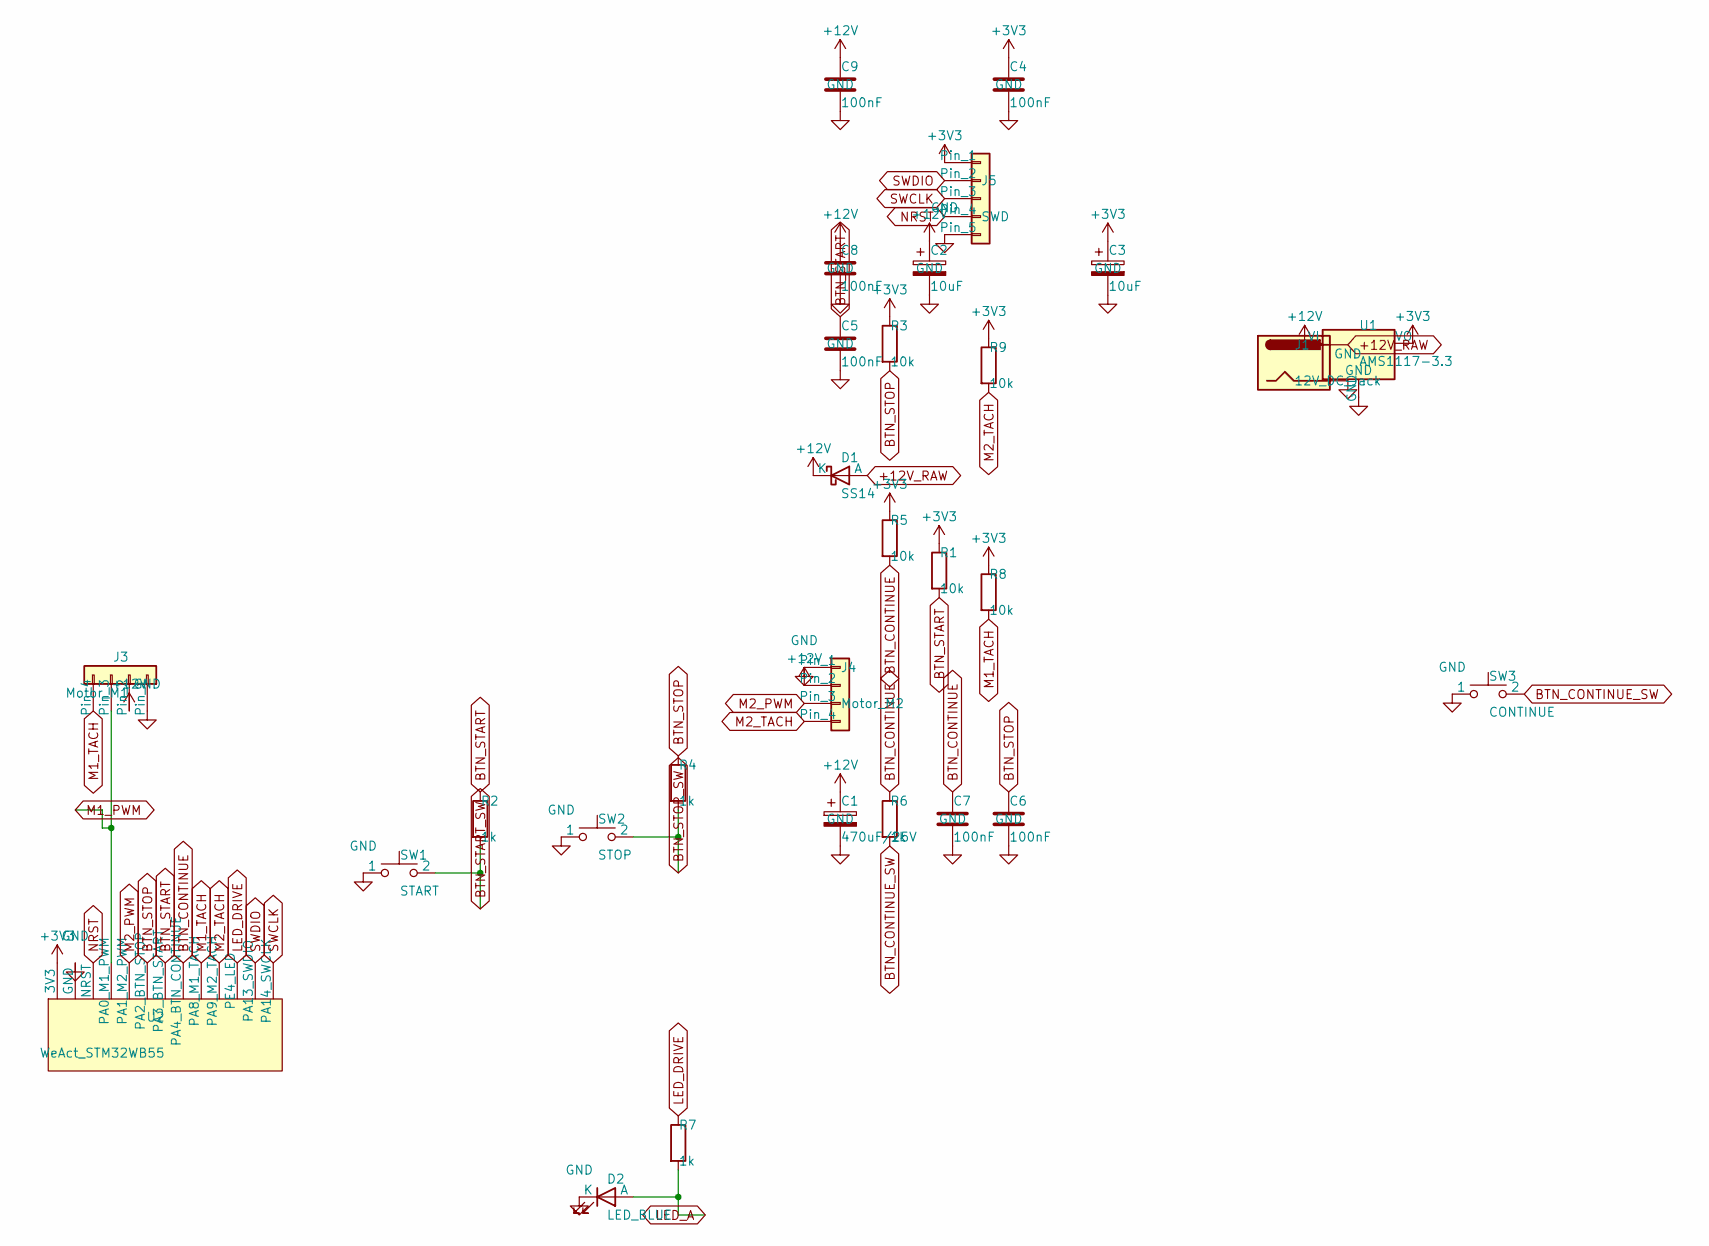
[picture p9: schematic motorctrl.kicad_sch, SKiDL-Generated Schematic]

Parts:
C1: 470uF/25V; CP_Radial_D8.0mm_P3.50mm
C2, C3: 10uF; CP_Elec_5x5.4
C4, C5, C6, C7, C8, C9: 100nF; C_0805_2012Metric
D1: SS14; D_SMA
D2: LED_BLUE; LED_0805_2012Metric
J1: 12V_DC_Jack; BarrelJack_Horizontal
J3: Motor_M1; PinHeader_1x04_P2.54mm_Vertical
J4: Motor_M2; PinHeader_1x04_P2.54mm_Vertical
J5: SWD; PinHeader_1x05_P2.54mm_Vertical
R1, R3, R5, R8, R9: 10k; R_0805_2012Metric
R2, R4, R6, R7: 1k; R_0805_2012Metric
SW1: START; SW_PUSH_6mm
SW2: STOP; SW_PUSH_6mm
SW3: CONTINUE; SW_PUSH_6mm
U1: AMS1117-3.3; SOT-223-3_TabPin2
U2: WeAct_STM32WB55; PinHeader_2x12_P2.54mm_Vertical

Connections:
+3V3: C3.1, C4.1, J5.1, R1.1, R3.1, R5.1, R8.1, R9.1, U1.2 (VO), U2.1 (3V3)
+12V: C1.1, C2.1, C8.1, C9.1, D1.1 (K), J3.2, J4.2, U1.3 (VI)
+12V_RAW: D1.2 (A), J1.1
BTN_CONTINUE: C7.1, R5.2, R6.1, U2.8 (PA4_BTN_CONTINUE)
BTN_CONTINUE_SW: R6.2, SW3.2
BTN_START: C5.1, R1.2, R2.1, U2.7 (PA3_BTN_START)
BTN_START_SW: R2.2, SW1.2
BTN_STOP: C6.1, R3.2, R4.1, U2.6 (PA2_BTN_STOP)
BTN_STOP_SW: R4.2, SW2.2
GND: C1.2, C2.2, C3.2, C4.2, C5.2, C6.2, C7.2, C8.2, C9.2, D2.1 (K), J1.2, J3.1, J4.1, J5.5, SW1.1, SW2.1, SW3.1, U1.1 (GND), U2.2 (GND)
LED_A: D2.2 (A), R7.2
LED_DRIVE: R7.1, U2.11 (PE4_LED)
M1_PWM: J3.3, U2.4 (PA0_M1_PWM)
M1_TACH: J3.4, R8.2, U2.9 (PA8_M1_TACH)
M2_PWM: J4.3, U2.5 (PA1_M2_PWM)
M2_TACH: J4.4, R9.2, U2.10 (PA9_M2_TACH)
NRST: J5.4, U2.3 (NRST)
SWCLK: J5.3, U2.13 (PA14_SWCLK)
SWDIO: J5.2, U2.12 (PA13_SWDIO)

Board: 2 copper layers, 29 parts (0 on the bottom side), 19 nets, no tracks yet.

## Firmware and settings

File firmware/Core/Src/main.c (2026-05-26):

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
/* Includes ------------------------------------------------------------------*/
#include "main.h"

IPCC_HandleTypeDef hipcc;

RTC_HandleTypeDef hrtc;

TIM_HandleTypeDef htim1;
TIM_HandleTypeDef htim2;
TIM_HandleTypeDef htim16;

/* USER CODE BEGIN PV */
/* Application-level timer handles:
 *   htim1  — tachometer input capture  (M1 = CH1 / PA8, M2 = CH2 / PA9)
 *   htim2  — 20 kHz PWM output          (M1 = CH1 / PA0, M2 = CH2 / PA1)
 *   htim16 — 100 ms PID control tick
 */
/* USER CODE END PV */

void SystemClock_Config(void);
void PeriphCommonClock_Config(void);
static void MX_GPIO_Init(void);
static void MX_IPCC_Init(void);
static void MX_RTC_Init(void);
static void MX_TIM1_Init(void);
static void MX_TIM2_Init(void);
static void MX_TIM16_Init(void);
static void MX_RF_Init(void);
/**
  * @brief  The application entry point.
  * @retval int
  */
int main(void)
{

  /* MCU Configuration--------------------------------------------------------*/

  /* Reset of all peripherals, Initializes the Flash interface and the Systick. */
  HAL_Init();
  /* Config code for STM32_WPAN (HSE Tuning must be done before system clock configuration) */
  MX_APPE_Config();

  /* Configure the system clock */
  SystemClock_Config();

  /* Configure the peripherals common clocks */
  PeriphCommonClock_Config();

  /* IPCC initialisation */
  MX_IPCC_Init();

  /* Initialize all configured peripherals */
  MX_GPIO_Init();
  MX_RTC_Init();
  MX_TIM1_Init();
  MX_TIM2_Init();
  MX_TIM16_Init();
  MX_RF_Init();
  /* Init code for STM32_WPAN */
  MX_APPE_Init();

  /* Infinite loop */
  /* USER CODE BEGIN WHILE */
  while (1)
  {
    /* USER CODE END WHILE */
    MX_APPE_Process();

    /* USER CODE BEGIN 3 */
  }
  /* USER CODE END 3 */
}

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


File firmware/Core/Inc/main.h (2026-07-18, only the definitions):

#define M1_PWM_Pin GPIO_PIN_0
#define M1_PWM_GPIO_Port GPIOA
#define M2_PWM_Pin GPIO_PIN_1
#define M2_PWM_GPIO_Port GPIOA
#define BTN_STOP_Pin GPIO_PIN_2
#define BTN_STOP_GPIO_Port GPIOA
#define BTN_STOP_EXTI_IRQn EXTI2_IRQn
#define BTN_START_Pin GPIO_PIN_3
#define BTN_START_GPIO_Port GPIOA
#define BTN_START_EXTI_IRQn EXTI3_IRQn
#define BTN_CONTINUE_Pin GPIO_PIN_4
#define BTN_CONTINUE_GPIO_Port GPIOA
#define BTN_CONTINUE_EXTI_IRQn EXTI4_IRQn
#define M1_TACHO_Pin GPIO_PIN_8
#define M1_TACHO_GPIO_Port GPIOA
#define M2_TACHO_Pin GPIO_PIN_9
#define M2_TACHO_GPIO_Port GPIOA
#define LED_BLUE_Pin GPIO_PIN_4
#define LED_BLUE_GPIO_Port GPIOE
#define htim_tacho  htim1   /* tachometer input capture: M1=CH1(PA8), M2=CH2(PA9) */
#define htim_pwm    htim2   /* 20 kHz BLDC motor PWM:   M1=CH1(PA0), M2=CH2(PA1) */
#define htim_pid    htim16  /* 100 ms PID control tick */
#define MODE_KHALED     0
#define MODE_TOON       1
#define MOTOR_MODE      MODE_KHALED   /* <<< switch here */
#define M1_PPR          MOTOR_PPR
#define M1_MIN_DUTY     MOTOR_MIN_DUTY
#define M1_SPEED        1200
#define M1_Kp           0.012f
#define M1_Ki           0.0f
#define M1_Kd           0.0f
#define M1_pwm_tim      htim2
#define M1_pwm_channel  TIM_CHANNEL_1
#define M1_ic_tim       htim1
#define M1_ic_channel   TIM_CHANNEL_1
#define M2_PPR          MOTOR_PPR
#define M2_MIN_DUTY     MOTOR_MIN_DUTY
#define M2_SPEED        1200
#define M2_Kp           0.012f
#define M2_Ki           0.0f
#define M2_Kd           0.0f
#define M2_pwm_tim      htim2
#define M2_pwm_channel  TIM_CHANNEL_2
#define M2_ic_tim       htim1
#define M2_ic_channel   TIM_CHANNEL_2
#define CYCLE_PERIOD    (35 * 10ul)   /* 350 ticks = 35 s */
#define PID_dt          0.1f
#define Mode_Stopped    0
#define Mode_Running    1
#define Mode_Continue   2
#define DEBOUNCE_MS     50

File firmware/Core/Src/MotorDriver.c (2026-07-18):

/*
 * MotorDriver.c — Phase 2 (STM32WB55, 64 MHz)
 * Ported from Phase 1 (STM32F103RB, 72 MHz)
 * Speed reporting is now via BLE telemetry; printf removed.
 */

#include "MotorDriver.h"

void Motor_Init(Motor_t *motor,
                TIM_HandleTypeDef *pwm_tim, uint32_t pwm_channel,
                TIM_HandleTypeDef *ic_tim,  uint32_t ic_channel,
                float kp, float ki, float kd,
                uint32_t ppr, float min_duty)
{
    motor->moving       = 0;
    motor->pwm_tim      = pwm_tim;
    motor->pwm_channel  = pwm_channel;
    motor->ic_tim       = ic_tim;
    motor->ic_channel   = ic_channel;
    motor->ppr          = ppr;
    motor->min_duty     = min_duty;

    /* IC glitch filter. The capture callback decimates by ppr (see
     * HAL_TIM_IC_CaptureCallback), so Motor_HandleICInterrupt runs once per
     * full REVOLUTION and diff always spans one revolution, whatever the ppr.
     * The shortest legitimate diff is therefore one revolution at
     * MOTOR_MAX_RPM, in prescaled ticks (prescaler ≈ 1000): 1280 ticks.
     * Anything shorter is sensor bounce/noise (the old fixed 72 let glitches
     * up to ~52,600 RPM through). */
    motor->min_diff_ticks = (TIM_CLOCK / 1000ul) * 60ul / MOTOR_MAX_RPM;

    motor->last_capture = 0;
    motor->period_ticks = 0;
    motor->pulses_count = 0;
    motor->speed_rpm    = 0;
    motor->setpoint_rpm = 0;
    motor->duty         = 0;
    motor->stale_ticks  = 0;

    motor->pid.Kp         = kp;
    motor->pid.Ki         = ki;
    motor->pid.Kd         = kd;
    motor->pid.integral   = 0.0f;
    motor->pid.prev_error = 0.0f;

    Motor_SetDuty(motor, 0);
    HAL_TIM_PWM_Start(motor->pwm_tim, motor->pwm_channel);
}

void Motor_Start(Motor_t *motor, float duty)
{
    motor->moving           = 0;
    motor->pulses_count     = 0;
    motor->speed_rpm        = 0;
    motor->stale_ticks      = 0;
    motor->pid.integral     = 0;
    motor->pid.prev_error   = 0;
    Motor_SetDuty(motor, duty);
    HAL_TIM_IC_Start_IT(motor->ic_tim, motor->ic_channel);
}

void Motor_Stop(Motor_t *motor)
{
    Motor_SetDuty(motor, 0.0f);
    motor->speed_rpm = 0;
    HAL_TIM_IC_Stop_IT(motor->ic_tim, motor->ic_channel);
}

void Motor_SetDuty(Motor_t *motor, float duty)
{
	 if (duty <0)    duty = 0;
    if (duty > MOTOR_MAX_DUTY) duty = MOTOR_MAX_DUTY;   /* debug: keep PWM below full scale */
    motor->duty = duty;
    uint32_t arr = motor->pwm_tim->Instance->ARR;
    uint32_t ccr = (uint32_t)((duty / 100.0f) * arr);
    __HAL_TIM_SET_COMPARE(motor->pwm_tim, motor->pwm_channel, ccr);
}

void Motor_SetTargetSpeed(Motor_t *motor, float rpm)
{
    motor->setpoint_rpm = (uint16_t)rpm;
}

void Motor_HandleICInterrupt(Motor_t *motor)
{
    uint32_t capture = HAL_TIM_ReadCapturedValue(motor->ic_tim, motor->ic_channel);

    uint32_t diff = (capture >= motor->last_capture) ?
                    (capture - motor->last_capture) :
                    ((motor->ic_tim->Instance->ARR - motor->last_capture) + capture);

    if (diff > motor->min_diff_ticks)
    {
        diff *= 1000; /* scale back to base-clock ticks (prescaler = 999 ≈ 1000) */
        motor->last_capture = capture;
        motor->period_ticks = diff;

        if (diff > 0 && motor->pulses_count > 0)
        {
            float freq        = (float)TIM_CLOCK / (float)diff;
            motor->speed_rpm  = (uint16_t)(freq * 60.0f);
        }
        motor->pulses_count++;   /* only real edges count toward rotations */
    }
}

void Motor_UpdatePID(Motor_t *motor, float dt_sec)
{
    /* Hold the last measured speed across ticks that had no pulse; only declare
     * 0 after SPEED_TIMEOUT_TICKS consecutive empty ticks (real stall/stop).
     * This stops the telemetry from dropping to 0 between pulses at low RPM. */
    if (motor->moving)
        motor->stale_ticks = 0;
    else if (++motor->stale_ticks >= SPEED_TIMEOUT_TICKS)
        motor->speed_rpm = 0;

    float error = (float)motor->setpoint_rpm - (float)motor->speed_rpm;

    motor->pid.integral += error * dt_sec;

    float derivative = (error - motor->pid.prev_error) / dt_sec;

    motor->duty += motor->pid.Kp * error
                 + motor->pid.Ki * motor->pid.integral
                 + motor->pid.Kd * derivative;

    if (motor->duty <  motor->min_duty)  motor->duty = motor->min_duty;
    if (motor->duty > MOTOR_MAX_DUTY)    motor->duty = MOTOR_MAX_DUTY;

    Motor_SetDuty(motor, motor->duty);
    motor->pid.prev_error = error;
    motor->moving = 0;
}

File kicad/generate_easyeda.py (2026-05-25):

#!/usr/bin/env python3
"""
generate_easyeda.py
Generates an EasyEDA Standard schematic JSON for the MotorCtrl board.

Run:    python generate_easyeda.py
Output: kicad/MotorCtrl_EasyEDA.json

Import into EasyEDA Standard (easyeda.com):
    File > Import > EasyEDA > select MotorCtrl_EasyEDA.json

After import:
  1. Zoom into each group and drag any net label that is not yet on a pin.
     EasyEDA highlights the pin in orange when your cursor is close enough — it snaps.
  2. J2A / J2B are placeholder headers for the WeAct STM32WB55 module.
     Search EasyEDA library for "WeAct STM32WB55" and replace them, or keep them as-is
     and annotate the pin names in the Value field.
  3. Run ERC (Inspect > ERC) — fix any "pin not connected" by snapping nearby labels.

All LCSC part numbers are valid — EasyEDA will auto-load symbols from the cloud.
"""

import json

# ─────────────────────────────────────────────────────────────
# ID generator (every shape in EasyEDA needs a unique ggeId)
# ─────────────────────────────────────────────────────────────
_id = 0
def gid():
    global _id
    _id += 1
    return f"gge{_id}"

shapes = []

# ─────────────────────────────────────────────────────────────
# Primitive helpers — append EasyEDA shape strings
# ─────────────────────────────────────────────────────────────

def comp(x, y, rot, pkg, lcsc, ref, val):
    """Component instance referencing EasyEDA cloud library by LCSC ID."""
    shapes.append(
        f"C~{x}~{y}~{rot}~{gid()}~0~{pkg}~{lcsc}~{ref}~{val}~1~~0~{gid()}~locked"
    )

def netlabel(x, y, net, rot=0):
    """Global net label — EasyEDA connects all labels with the same name."""
    shapes.append(
        f"N~{x}~{y}~{rot}~{gid()}~{net}~0~normal~{gid()}~locked"
    )

def pwrflag(x, y, net):
    """Power symbol (needed on every power rail so ERC sees it as driven)."""
    shapes.append(
        f"PF~{x}~{y}~0~{gid()}~{net}~~{gid()}~locked"
    )

def text(x, y, txt, size=14):
    """Section title text."""
    shapes.append(
        f"T~L~{x}~{y}~0~1~0~arial~{size}~bold~normal~#336699~{txt}~{gid()}~locked"
    )


# ─────────────────────────────────────────────────────────────
# SECTION: POWER INPUT  (top-left, x=100-720, y=100-540)
# ─────────────────────────────────────────────────────────────
text(100, 70, "POWER INPUT")

# J1 — DC Barrel Jack 2.1mm centre-positive
# LCSC C16214 (DC-005)   pin1=centre(+)  pin2=ring(-)  pin3=switch(NC)
comp(180, 200, 0, "DC-005", "C16214", "J1", "DC_JACK_12V")
netlabel(140, 200, "+12V_RAW", 180)  # pin1 centre+
netlabel(180, 232, "GND")            # pin2 ring-
# pin3 switch: add a no-connect flag manually in EasyEDA

# D1 — Schottky diode 1N5819  reverse-polarity protection
# LCSC C8598 (SOD-123)   Anode(A) left  Cathode(K) right
comp(340, 200, 0, "SOD-123FL", "C8598", "D1", "1N5819")
netlabel(310, 200, "+12V_RAW", 180)  # Anode
netlabel(372, 200, "+12V")           # Cathode = protected +12 V

pwrflag(420, 155, "+12V")

# C1 — 470 µF / 25 V bulk electrolytic
# LCSC C176178   pin1=(+) top   pin2=(-) bottom
comp(260, 420, 0, "CAP-TH_BD8.0-P3.50", "C176178", "C1", "470uF/25V")
netlabel(260, 385, "+12V")
netlabel(260, 458, "GND")

# U1 — AMS1117-3.3 LDO  SOT-223
# LCSC C6186   pin1=GND  pin2=OUT  pin3=IN
comp(520, 290, 0, "SOT-223-3_L6.5-W3.4-P2.30-LS7.0-BR", "C6186", "U1", "AMS1117-3.3")
netlabel(478, 290, "GND")       # pin1
netlabel(562, 278, "+3V3")      # pin2 OUT
netlabel(562, 302, "+12V")      # pin3 IN

# C4 — 10 µF LDO input bypass  C0805
# LCSC C19702
comp(460, 430, 0, "C0805", "C19702", "C4", "10uF")
netlabel(460, 398, "+12V")
netlabel(460, 462, "GND")

# C5 — 10 µF LDO output bypass  C0805
comp(580, 430, 0, "C0805", "C19702", "C5", "10uF")
netlabel(580, 398, "+3V3")
netlabel(580, 462, "GND")

# C6 — 100 nF output decoupling  C0402
# LCSC C1525
comp(660, 430, 0, "C0402", "C1525", "C6", "100nF")
netlabel(660, 398, "+3V3")
netlabel(660, 462, "GND")

pwrflag(700, 380, "+3V3")
pwrflag(120, 490, "GND")


# ─────────────────────────────────────────────────────────────
# SECTION: STM32WB55 MODULE  (centre, x=760-1080, y=100-600)
# Split into two placeholder headers; replace with real WeAct symbol later.
# ─────────────────────────────────────────────────────────────
text(760, 70, "STM32WB55 MODULE (U2)")
text(760, 90, "  -> replace J2A/J2B with WeAct symbol")

# J2A — left pin row  (3V3, GND, NRST, PA0-PA3)
# LCSC C124378  7-pin 2.54 mm single-row male header
comp(830, 480, 0, "HDR-TH_7P-P2.54-V-M", "C124378", "J2A", "WB55_LEFT")
# Vertical header: pin 1 at top, pins 20 units apart
netlabel(798, 418, "+3V3")          # pin1
netlabel(798, 438, "GND")           # pin2
netlabel(798, 458, "NRST")          # pin3
netlabel(798, 478, "M1_PWM")        # pin4  PA0
netlabel(798, 498, "M2_PWM")        # pin5  PA1
netlabel(798, 518, "BTN_STOP")      # pin6  PA2
netlabel(798, 538, "BTN_START")     # pin7  PA3

# J2B — right pin row  (PA4, PA8, PA9, PE4, PA13, PA14)
# LCSC C124377  6-pin 2.54 mm single-row male header
comp(1010, 460, 0, "HDR-TH_6P-P2.54-V-M", "C124377", "J2B", "WB55_RIGHT")
netlabel(1042, 428, "BTN_CONTINUE") # pin1  PA4
netlabel(1042, 448, "M1_TACH")      # pin2  PA8
netlabel(1042, 468, "M2_TACH")      # pin3  PA9
netlabel(1042, 488, "LED_DRIVE")    # pin4  PE4
netlabel(1042, 508, "SWDIO")        # pin5  PA13
netlabel(1042, 528, "SWCLK")        # pin6  PA14


# ─────────────────────────────────────────────────────────────
# SECTION: MOTOR OUTPUTS  (top-right, x=1100-1600, y=100-520)
# ─────────────────────────────────────────────────────────────
text(1100, 70, "MOTOR OUTPUTS")

# R1 — M1 tacho pull-up 10 kΩ  (rotation=90 → vertical)
# LCSC C25804
comp(1180, 170, 90, "R0402", "C25804", "R1", "10k")
netlabel(1180, 140, "+3V3")
netlabel(1180, 200, "M1_TACH")

# R2 — M2 tacho pull-up 10 kΩ
comp(1280, 170, 90, "R0402", "C25804", "R2", "10k")
netlabel(1280, 140, "+3V3")
netlabel(1280, 200, "M2_TACH")

# C2 — M1 motor power decoupling 100 nF
comp(1150, 340, 0, "C0402", "C1525", "C2", "100nF")
netlabel(1150, 308, "+12V")
netlabel(1150, 372, "GND")

# C3 — M2 motor power decoupling 100 nF
comp(1260, 340, 0, "C0402", "C1525", "C3", "100nF")
netlabel(1260, 308, "+12V")
netlabel(1260, 372, "GND")

# J3 — Motor M1 connector  KF2510 4-pin
# Pin order: 1=GND, 2=+12V, 3=M1_PWM, 4=M1_TACH
# LCSC C225517
comp(1520, 230, 0, "KF2510-4P", "C225517", "J3", "M1_CONN")
netlabel(1552, 208, "GND")
netlabel(1552, 224, "+12V")
netlabel(1552, 240, "M1_PWM")
netlabel(1552, 256, "M1_TACH")

# J4 — Motor M2 connector  KF2510 4-pin
comp(1520, 430, 0, "KF2510-4P", "C225517", "J4", "M2_CONN")
netlabel(1552, 408, "GND")
netlabel(1552, 424, "+12V")
netlabel(1552, 440, "M2_PWM")
netlabel(1552, 456, "M2_TACH")


# ─────────────────────────────────────────────────────────────
# SECTION: BUTTONS  (bottom, y=650-1050)
# Per-button circuit: 10k pull-up R + 100nF debounce C + 100R series R + tactile SW
# ─────────────────────────────────────────────────────────────
text(100, 630, "BUTTONS")
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

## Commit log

2026-05-01 Initial commit: STM32WB55 dual BLDC motor controller — Phase 2 scaffold
    Phase 2 of a dual BLDC motor controller project.
    Hardware: WeAct STM32WB55 board (BLE 5.0 + Cortex-M4).
    BLE GATT services scaffolded via STM32CubeMX + STM32_WPAN:
    - Control service (0x0001): TargetSpeedM1, TargetSpeedM2, CycleTime, Command
    - Telemetry service (0x0010): ActualSpeedM1, ActualSpeedM2, RotationsM1, RotationsM2, ElapsedTime
    Peripherals configured:
    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
2026-05-01 Port Phase 1 motor control firmware to STM32WB55 (Phase 2)
    - Add MotorDriver.h / MotorDriver.c ported from Phase 1 (F103RB → WB55):
    TIM_CLOCK updated to 64 MHz, printf removed (telemetry goes via BLE)
    - main.h: add motor config defines (PID constants, speed defaults,
    timer mappings, cycle period, mode enum, debounce threshold)
    - app_conf.h: add CFG_TASK_MOTOR_TELE_ID sequencer task for safe
    BLE characteristic updates from timer ISR context
    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
2026-05-01 Add IC noise filter and LED debug indicators for hardware testing
    - TIM1 IC filter: 0 → 15 (max) to match Phase 1 and suppress tacho noise
    - LED_BLUE ON when motors start, OFF when motors stop
    - LED_BLUE toggles every PID tick (100 ms) as a running heartbeat
    [custom_app.c, main.c]
2026-05-02 Add application-context comments to peripheral init functions in main.c
    Replace generic CubeMX labels with business descriptions inside USER CODE
    sections (survive regeneration):
    - PV: timer handle roles (tacho / PWM / PID tick)
    - Peripheral init call-site: inline role labels on each MX_xxx_Init() call
    - TIM1: tachometer IC for M1/M2, pin mapping, 64 kHz effective clock
    - TIM2: 20 kHz PWM for M1/M2, active-LOW polarity rationale
    - TIM16: 100 ms PID tick, start/stop lifecycle
    - GPIO: button roles (STOP/START/CONTINUE), debounce note, LED behaviour
    [main.c]
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2026-05-09 Import project into STM32CubeIDE — build verified, not yet tested on hardware
    Adds CubeIDE-generated files (startup, syscalls, sysmem, linker scripts, debug
    launch config) and removes unused CMSIS/HAL/Middleware templates for non-WB55
    device variants that CubeMX had included but STM32CubeIDE does not need.
2026-05-12 Fix BLE bring-up: add missing IPCC IRQ handlers + cleanups
    - Add IPCC_C1_RX_IRQHandler and IPCC_C1_TX_IRQHandler in stm32wbxx_it.c
    bridging to HW_IPCC_Rx_Handler / HW_IPCC_Tx_Handler. Without these,
    CM0+ events never reached CM4 (landed in Default_Handler infinite loop)
    and BLE never advertised.
    - Fix HAL_GPIO_EXTI_Callback debounce: stamp last_X on every edge that
    clears the time window, regardless of mode check, so bounces are
    filtered even when the mode guard rejects the action.
    - Move BTN_CONTINUE release detection from TIM16 polling to both-edge
    EXTI with pin-state read in HAL_GPIO_EXTI_Callback.
    - Align advertised name with CFG_GAP_DEVICE_NAME ("MotorCtrl", 9 chars).
    - Add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
    [Phase2.ioc, custom_app.c, main.c]
2026-05-24 Add BLE STATUS run-state char, read-from-source GATT reads, build-mode switch
    - STATUS characteristic (Telemetry service, UUID 0x0016, READ+NOTIFY, 1 byte:
    0=idle, 1=timed, 2=continuous). Added manually in code because the CubeMX
    GATT designer caps STM32WB services at 5 chars; max_attr_record bumped
    21->25. Firmware notifies on every run-state transition — BLE command,
    timed auto-stop, and physical buttons — via the telemetry sequencer task
    (ISR-safe; never calls aci_* from an ISR).
    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
2026-05-25 docs: add Phase 2 delivery guide; fix button wiring in connections.html
    - docs/phase2_delivery.md: client-facing Phase 2 delivery document modeled on
    the encoder project's phase1_delivery.md — scope, hardware BOM, connections,
    Khaled/Toon build modes, firmware + CPU2 BLE-stack flashing, BLE GATT
    reference (incl. STATUS char), Web Bluetooth dashboard usage, operation,
    troubleshooting, and deferred items.
    - connections.html: correct the push-button section to active-HIGH with the
    MCU internal pull-down (button common to +3V3), matching the firmware, and
    flag that the SKiDL source needs the same change.
2026-05-25 docs: add styled HTML render of the Phase 2 delivery doc
    Standalone phase2_delivery.html mirroring the encoder project's
    phase1_delivery.html style — same content as phase2_delivery.md rendered
    with proper HTML tables, code blocks, and lists.
2026-05-25 restructure: move firmware into firmware/, connections.html into docs/
    Monorepo prep: relocate the STM32 project under firmware/ (history preserved
    via git mv), move connections.html into docs/, and extend .gitignore for
    workspace metadata, KiCad backups/.history, and local config.
2026-05-25 monorepo: bring WebApp and KiCad under version control
    Repo root is now Phase2-Project/, containing firmware/, WebApp/, kicad/, and
    docs/ (the firmware git history + remote are preserved — same .git, relocated).
    WebApp (Web Bluetooth dashboard) and the KiCad hardware design are now tracked;
    backups, .history, zips, and workspace metadata stay ignored.
    [MotorCtrl - Copy.kicad_sch, MotorCtrl.kicad_pcb, MotorCtrl_EasyEDA.json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]
2026-05-25 docs: add monorepo root README (GitHub landing page)
    Project overview, repo layout, hardware/BLE GATT summary (incl. STATUS char),
    CubeIDE build + CPU2 BLE-stack flashing, build modes, and dashboard quick
    start. Links to docs/phase2_delivery.md for the full delivery doc.
2026-05-26 fix(firmware): stop CONTINUE button by polling level, not EXTI edge
    The CONTINUE button (PA4, "run while held") failed to stop on release.
    Root cause: release was detected on a falling EXTI edge, but the ISR
    inferred press/release from the pin level sampled after the edge. During
    a bouncing transition that read could catch a transient HIGH, misclassify
    the release as a press, then the 50 ms first-edge-wins lockout swallowed
    the settling-LOW edge. With detection being edge-only, a pin sitting at a
    static LOW could never recover, so the motor stayed running.
    Fix: treat "run while held" as level-semantic.
    - PA4 EXTI is now rising-only (press starts Continue); the falling edge is
    gone.
    - The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
    [custom_app.c, main.c]
2026-05-26 feat(firmware): count Elapsed time during Continue mode
    cycle_timer (the ET telemetry source) previously only advanced in the
    timed Mode_Running, so the dashboard's Elapsed field stayed at 00:00 for
    the whole of Continue mode. Increment it in both running modes so ET
    reflects run-time during Continue too; the cycle-limit auto-stop check
    still applies only to the timed mode. Clamp at uint16 max so a long
    web-latched Continue run reads "maxed" rather than wrapping back to 0
    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
2026-05-26 fix(webapp): redraw chart when page returns from background
    On mobile, switching apps backgrounds the tab and can leave the Chart.js
    canvas sized to a stale/zero dimension; because the container's CSS size
    is unchanged on return, no resize event fires and the chart redraws tiny
    in the corner. Force chart.resize()+update() (deferred one frame) on
    visibilitychange-visible and pageshow so it restores to full size.
2026-05-26 docs: add live dashboard link and current status to README
    Add the GitHub Pages URL (hosted dashboard, no install) near the top and
    under "Run the dashboard", and clarify Continuous-mode semantics (CONTINUE
    button is momentary/run-while-held; app command is latched until Stop).
2026-05-29 feat(firmware): PPR=1 for Khaled, per-mode min-duty, speed-hold telemetry
    - MODE_KHALED PPR set to 1 (new motor measured 1 tacho pulse/rev)
    - MOTOR_MIN_DUTY now mode-specific (Khaled 0, Toon 20), passed into
    Motor_Init as a per-motor min_duty and enforced only in the PID floor
    so a STOP still drives duty to 0
    - speed-hold: hold last RPM across pulse-less PID ticks, declaring 0 only
    after SPEED_TIMEOUT_TICKS (2 s) — fixes telemetry dropping to 0 between
    pulses at low/mid RPM with PPR=1
    [MotorDriver.c, custom_app.c, main.h]
2026-05-29 feat(webapp): count-up time axis + Set-button flash feedback
    - Live Speed x-axis now counts elapsed seconds (0s,10s,20s...) from a
    fixed first-sample anchor instead of sliding negative offsets vs now;
    Clear resets the anchor to 0s
    - Set buttons flash a green (ok) / red (fail) ring on press; ring outline
    means no layout shift
2026-05-29 feat(webapp): clearer Set log wording
    Log writes as 'Set M1 target = 500 RPM' / 'Set cycle time = 35 s' instead
    of the terser 'Set TSM1 = 500' / 'Set CT = 35s'.
2026-05-29 feat(webapp): per-motor RPM colors — dual colored Y-axes + colored readouts
    - Split the single Y-axis into y1 (left, M1 sky-blue) and y2 (right, M2
    amber); each motor's Actual+Target bind to its own colored axis. Right
    axis skips gridlines to avoid doubling over the left.
    - Big M1/M2 RPM readouts now use the matching line colors (sky-400 /
    amber-500), so number, axis and trace share one color per motor.
2026-05-30 fix(webapp): constant-width time window so the curve scrolls at a steady speed
    Pin the chart x-axis to a fixed 60s window (min=now-60s, max=now) on every
    update instead of letting it auto-grow from the first samples. Previously the
    axis was zoomed into the few seconds of initial data, so the curve raced at
    startup before settling. Now it scrolls at one speed from the first sample;
    ticks before the first sample render blank.
2026-07-17 fix(webapp): keep Stop usable + self-heal dropped Status notifications
    Ported from Vaneiges/MotorCtrl-ble-STM32 f10aca5 (tested repo copy):
    - Stop button enabled whenever connected, not gated on reported run-state
    - Re-read Status 400 ms after every command (firmware only notifies on change)
    - 3 s heartbeat poll of Status while connected
2026-07-17 fix(webapp): round elapsed-time ticks on the chart (0s, 10s, 20s...)
    X values were epoch ms relabeled as elapsed seconds, so Chart.js's 'nice' tick positions were arbitrary in elapsed time (8s, 18s, 35s) and the 0s tick fell before the first sample and was blanked. Store X directly as elapsed seconds from chart._t0: ticks land on round seconds including 0s, the fixed 0-60s window fills before scrolling, and the stray window-edge tick is dropped (includeBounds: false).
2026-07-18 fix(firmware): PPR-aware tacho glitch filter derived from MOTOR_MAX_RPM
    The IC glitch filter was a fixed 72 prescaled ticks, tuned for the old high-PPR sensor - it only rejected edges implying >52,600 RPM, so sensor bounce produced ~50k RPM spikes in telemetry (and phantom rotation counts). The threshold is now computed in Motor_Init as one revolution at MOTOR_MAX_RPM (3000): 1280 ticks. Since the capture callback decimates by ppr, the measured interval is always one revolution, so the threshold is PPR-independent. Rejected captures no longer increment pulses_count either.
    Verified on hardware: flashed, spikes gone, PID tracking unaffected.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
    [MotorDriver.c]
2026-07-18 feat(webapp): editable board name stored in the dashboard (v1.2.0)
    CSV export task 1/5 (Toon spec, Option A): the Board card title is now a text input, persisted in localStorage (mc_boardName, default 'Board One'). It will label CSV rows and filenames in the coming 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
2026-07-18 fix(webapp): connection status pill shows the custom board name (v1.2.1)
    The status pill said 'Connected - MotorCtrl' (raw BLE device name) while the card title showed the custom board name - inconsistent once renamed. Pill now shows the custom name; the real BLE name is logged instead for debugging. Renaming while connected updates the pill live.
2026-07-18 feat(webapp): per-cycle recorder for CSV export (v1.3.0)
    CSV export task 2/5 (Toon spec). Buffers one row per telemetry tick (asm1 notification, ~100 ms) from cycle start (idle->running) to cycle end (running->idle), covering timed auto-stop, continuous+St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
    No export UI yet - this task only proves recording works; check the log line 'Cycle recorded: N samples (M s)' after a test run.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
2026-07-18 feat(webapp): auto-export completed cycles on desktop Chrome/Edge (v1.6.0)
    CSV export task 5/5 (Toon: 'incorporate automatic export for Windows / Linux Chrome'). New Auto-export checkbox, shown only when window.showDirectoryPicker exists (File System Access API - desktop Chromium browsers; absent on Android/iOS/Safari/Firefox, where only the manual Export CSV button applies). Enabling it prompts for a folder once; every cycle completion afterward writes its CSV there silently, using the same format resolution as manual export. On write failure (permission revoked, folder moved) auto-export disables itself with a log line rather than failing silently on every future cycle; the manual button k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

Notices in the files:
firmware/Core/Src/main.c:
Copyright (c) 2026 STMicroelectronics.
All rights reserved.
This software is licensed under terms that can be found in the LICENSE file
